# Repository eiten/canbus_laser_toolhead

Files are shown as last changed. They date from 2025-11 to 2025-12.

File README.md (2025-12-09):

# 🔥 Laser CANbus Toolhead PCB

> 🌍 **Languages:** [English](README.md) | [Deutsch](README.de.md)

A compact, robust toolhead board for Klipper-based laser engravers and cutters (CoreXY). This board integrates power supply, laser driver logic, CAN-Bus communication, and input shaping (ICM-20602) in the smallest possible space.

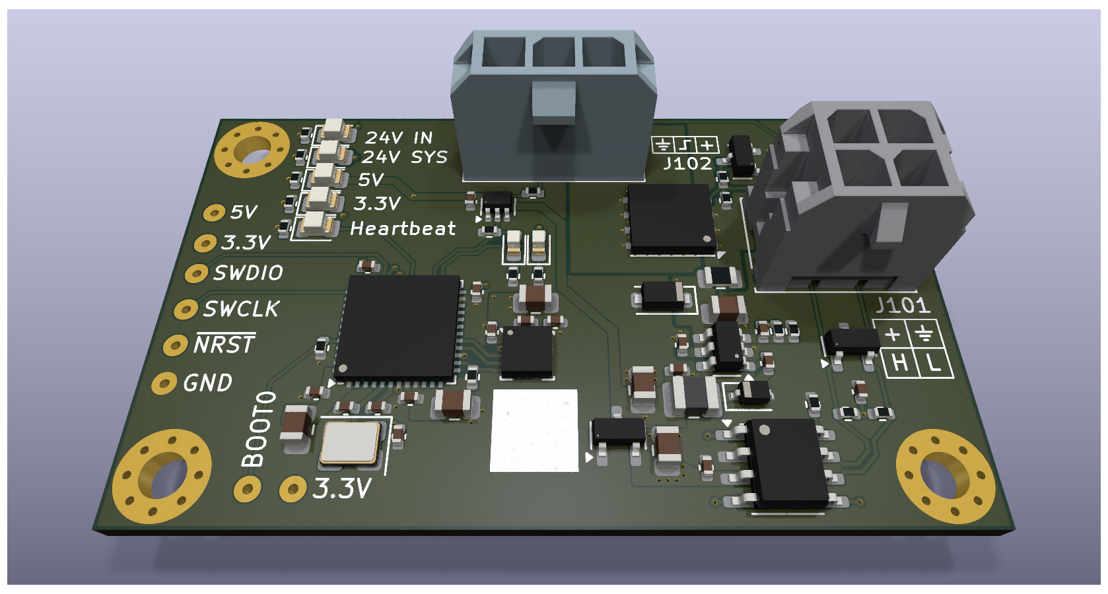
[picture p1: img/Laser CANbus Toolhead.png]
Laser CANbus Toolhead PCB


## 📚 Contents

<!-- @import "[TOC]" {cmd="toc" depthFrom=1 depthTo=6 orderedList=false} -->

<!-- code_chunk_output -->

- [🔥 Laser CANbus Toolhead PCB](#-laser-canbus-toolhead-pcb)
  - [📚 Contents](#-contents)
  - [✨ Features](#-features)
    - [🧠 Microcontroller](#-microcontroller)
    - [🔗 CAN-Bus Communication](#-can-bus-communication)
    - [📊 Input Shaping](#-input-shaping)
    - [⚡ Laser Power Control](#-laser-power-control)
    - [🎛️ Laser Signal Control](#️-laser-signal-control)
    - [🔌 Power Supply](#-power-supply)
    - [🚨 Diagnostics & Monitoring](#-diagnostics--monitoring)
  - [📋 Klipper Configuration](#-klipper-configuration)
    - [Basic MCU Setup](#basic-mcu-setup)
    - [Input Shaping (ICM-20602)](#input-shaping-icm-20602)
    - [Laser Control](#laser-control)
  - [🔌 Pinout & Connector Assignment](#-pinout--connector-assignment)
    - [J101 - Power & CAN Input (Micro-Fit 3.0, 2x2, THT)](#j101---power--can-input-micro-fit-30-2x2-tht)
    - [J102 - Laser Output (Micro-Fit 3.0, 1x3, THT)](#j102---laser-output-micro-fit-30-1x3-tht)
    - [Debug/Programming Header (Back Side)](#debugprogramming-header-back-side)
  - [🔧 Installation & Setup](#-installation--setup)
    - [1. CAN-Bus Configuration](#1-can-bus-configuration)
    - [2. Firmware Flash](#2-firmware-flash)
    - [3. Find UUID](#3-find-uuid)
  - [⚠️ Safety Notes](#️-safety-notes)
  - [🛠️ BOM (Bill of Materials) - Highlights](#️-bom-bill-of-materials---highlights)
  - [🛠️ Technical Specifications](#️-technical-specifications)
  - [📝 Changelog](#-changelog)
    - [Rev. 1](#rev-1)
    - [Rev. 0 (Initial Release)](#rev-0-initial-release)
  - [📚 Additional Resources](#-additional-resources)
  - [License](#license)

<!-- /code_chunk_output -->

## ✨ Features

### 🧠 Microcontroller
- **MCU:** STM32F072CBU6 (Cortex-M0, 48MHz, CAN-capable)
- **Stability:** 12MHz crystal for maximum CAN-Bus stability
- **Firmware:** Klipper-compatible

### 🔗 CAN-Bus Communication
- **Transceiver:** SN65HVD230 with ESD protection
- **Termination:** Split termination via solder jumper
- **Slope Control:** Switchable for EMI optimization

### 📊 Input Shaping
- **Sensor:** On-board ICM-20602 accelerometer/gyroscope (SPI)
- **Purpose:** Klipper resonance measurement for perfect print quality
- **Advantage:** Better availability and modern sensor technology

### ⚡ Laser Power Control
- **Circuit:** 24V / 6A High-Side Switch (CJAC70P06 P-MOSFET, 60V rated)
- **Peak Current:** 8A capability
- **Soft-Start:** Limits inrush current (Rise-time ~1.2ms)
- **Safety:** Hardware pull-down prevents unwanted activation
- **Limitation:** Max 6A limited by Micro Fit 3.0 connector with 0.75mm² wire

### 🎛️ Laser Signal Control
- **PWM:** 5V Level-shifted via 74AHCT1G125 buffer
- **Quality:** Clean edges, true hardware PWM via STM32 timer
- **Compatibility:** Common diode lasers

### 🔌 Power Supply
- **Input:** 24V with 250mA PTC fuse and SMF24A TVS diode
- **5V Rail:** MP2459 Buck converter (up to 60V input tolerant)
- **3.3V Rail:** XC6206 LDO for MCU and peripherals

### 🚨 Diagnostics & Monitoring
- **Power LEDs:** 24V In, 24V Sys, 5V, 3.3V
- **Status LEDs:** Laser Enable, Laser PWM, Heartbeat

## 📋 Klipper Configuration

### Basic MCU Setup
```ini
[mcu toolhead]
canbus_uuid: <your-uuid>  # Find with "ls /dev/serial/by-id/*" or "~/klippy-env/bin/python ~/klipper/scripts/canbus_query.py can0"

[temperature_sensor toolhead_mcu]
sensor_type: temperature_mcu
sensor_mcu: toolhead
```

### Input Shaping (ICM-20602)
```ini
[mpu9250]
cs_pin: toolhead:PA4
spi_bus: spi1
#axes_map: x,y,z  # Configure according to your printer orientation

[resonance_tester]
accel_chip: mpu9250
probe_points:
    150, 150, 20  # Adjust to your bed size
```

### Laser Control
```ini
# Laser PWM Signal
[output_pin laser_pwm]
pin: toolhead:PB14
pwm: True
cycle_time: 0.001          # 1kHz PWM frequency
shutdown_value: 0          # Safety: laser off during emergency

# Laser Enable (optional)
[output_pin laser_enable]
pin: toolhead:PB15
value: 0
shutdown_value: 0

# Heartbeat LED (optional)
[output_pin heartbeat]
pin: toolhead:PA9
pwm: True
cycle_time: 1.0
```

## 🔌 Pinout & Connector Assignment

### J101 - Power & CAN Input (Micro-Fit 3.0, 2x2, THT)
| Pin | Signal | Description |
|-----|---|---|
| 1 | **+24V** | Main power input (High Current) |
| 2 | **GND** | Ground |
| 3 | **CAN_H** | CAN-Bus High Signal |
| 4 | **CAN_L** | CAN-Bus Low Signal |

### J102 - Laser Output (Micro-Fit 3.0, 1x3, THT)
| Pin | Signal | Description |
|-----|---|---|
| 1 | **GND** | Laser Ground |
| 2 | **PWM** | 5V PWM Signal (Level-Shifted) |
| 3 | **+24V** | Switched Laser Power (Soft-Start) |

### Debug/Programming Header (Back Side)
| Pad | Pin | Signal | Function |
|-----|-----|---|---|
| 1 | - | **5V** | 5V Supply (from Programmer) |
| 2 | - | **3.3V** | VTref (Reference Voltage) |
| 3 | PA13 | **SWDIO** | Serial Wire Debug I/O |
| 4 | PA14 | **SWCLK** | Serial Wire Debug Clock |
| 5 | - | **NRST** | Reset Signal |
| 6 | - | **GND** | Ground |

> **💡 Bootloader Mode:** To force the STM32 into DFU/Bootloader mode (e.g., for initial flash with Katapult), bridge the **BOOT0** pad with **3.3V** during power-on.

## 🔧 Installation & Setup

### 1. CAN-Bus Configuration
- Set CAN-Bus termination according to position in network
- Baud rate: 1 Mbit/s (Klipper standard)

### 2. Firmware Flash
1. Put board into DFU mode (bridge BOOT0)
2. Compile Klipper for STM32F072 with CAN support
3. Flash firmware: `make flash FLASH_DEVICE=<dfu-device>`

### 3. Find UUID
```bash
~/klippy-env/bin/python ~/klipper/scripts/canbus_query.py can0
```

## ⚠️ Safety Notes

- **Laser Safety:** Always wear protective eyewear
- **Power Supply:** Only operate with 24V DC
- **Initial Setup:** Slowly ramp up laser power
- **Emergency:** Hardware pull-down ensures safe state

## 🛠️ BOM (Bill of Materials) - Highlights

| Component | Value/Type | Function | Package | Order Code |
|---|---|---|---|---|
| **U101** | STM32F072CBU6 | Main Microcontroller | UFQFPN-48 | STM32F072CBU6 |
| **U102** | MP2459GJ-Z | Buck Converter 24V→5V | TSOT-23-8 | MP2459GJ-Z |
| **U105** | SN65HVD230DR | CAN-Bus Transceiver | SOIC-8 | SN65HVD230DR |
| **U106** | ICM-20602 | 6-Axis IMU (Accelerometer/Gyroscope) | LGA-16 | ICM-20602 |
| **Q101** | CJAC70P06 | P-MOSFET (Laser Switch, 60V) | SOIC-8 | CJAC70P06 |
| **D101** | SMF24A | TVS Diode (Overvoltage Protection) | DO-214AC | SMF24A |
| **F101** | 1812L025 | PTC Fuse 250mA | 1812 | 1812L025 |
| **Y101** | 12MHz | Crystal for CAN Stability | HC-49/S | 12MHz Crystal |
| **J101/J102** | Micro-Fit 3.0 | THT Connectors | THT | Micro-Fit 3.0 THT |

## 🛠️ Technical Specifications

| Parameter | Value | Unit |
|---|---|---|
| **Input Voltage** | 24 ± 2 | V |
| **Laser Current (max)** | 4 | A |
| **CAN Baud Rate** | 1 | Mbit/s |
| **PWM Frequency** | 1 | kHz |
| **Soft-Start Time** | ~1.2 | ms |
| **Operating Temperature** | -10 to +70 | °C |
| **Dimensions** | TBD | mm |

## 📝 Changelog

### Rev. 0.1
- **Transistor Upgrade:** Replaced MOSFET with CJAC70P06 (60V voltage rating)
- **Sensor Upgrade:** Changed from ADXL345 to ICM-20602 (better availability, modern 6-axis IMU)
- **Connector Change:** Micro Fit 3.0 connectors changed from SMD to THT mounting
- **Silkscreen Enhancement:** Added connector pin assignments to silkscreen for easier assembly
- **Layout Improvements:** Cleaned up component placement and optimized routing
- **Documentation:** Updated overview image to reflect current design
- **BOM Update:** Added component order numbers and updated production data
- **Production Files:** Updated assembly and production files with current components

### Rev. 0.0 (Initial Release)
- Initial PCB design with STM32F072CBU6 microcontroller
- CAN-Bus communication with SN65HVD230 transceiver
- 24V/4A laser power control with AO4407A MOSFET
- ADXL345 accelerometer for input shaping
- MP2459 buck converter for power supply

## 📚 Additional Resources

- [Klipper Documentation](https://www.klipper3d.org/Config_Reference.html)
- [CAN-Bus Setup Guide](https://www.klipper3d.org/CANBUS.html)
- [Input Shaping](https://www.klipper3d.org/Resonance_Compensation.html)
- [Katapult Firmware Flasher](https://github.com/Arksine/katapult)

## License

This project is licensed under the **Creative Commons Attribution-NonCommercial-ShareAlike 4.0 International License** (CC BY-NC-SA 4.0).



This means you are free to:
- **Share** — copy and redistribute the material in any medium or format
- **Adapt** — remix, transform, and build upon the material

Under the following terms:
- **Attribution** — You must give appropriate credit, provide a link to the license, and indicate if changes were made
- **NonCommercial** — You may not use the material for commercial purposes
- **ShareAlike** — If you remix, transform, or build upon the material, you must distribute your contributions under the same license

For the full license text, visit: https://creativecommons.org/licenses/by-nc-sa/4.0/

---

> **Note:** The original documentation is in German ([README.de.md](README.de.md)). This English version is a translation for international users.

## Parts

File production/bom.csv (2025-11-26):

Designator | Footprint | Quantity | Value | LCSC Part #
C101, C102, C115 | 0402 | 3 | 33p | C1562
C103, C110, C116, C121, C124 | 0805 | 5 | 10u | C440198
C104, C105, C106, C107, C108, C109, C111, C113, C114, C117, C118, C120, C122, C123 | 0402 | 14 | 100n | C307331
C112 | 0805 | 1 | 22u | C45783
C119 | 0402 | 1 | 4n7 | C1538
D101 | D_SOD-123F | 1 | SMF24A | C19077514
D102 | D_SOD-323 | 1 | 1N5819WS | C191023
D103 | SOT-23 | 1 | PESD1CAN | C343993
D104, D105, D106, D107 | 0805 | 4 | green | C2297
D108 | 0805 | 1 | yellow | C2296
D109, D110 | 0603 | 2 | red | C2286
F101 | 0805 | 1 | 250mA | C20608679
J101 | Molex_Micro-Fit_3.0_43045-0412_2x02_P3.00mm_Vertical | 1 | In | C492540
J102 | Molex_Micro-Fit_3.0_43650-0315_1x03_P3.00mm_Vertical | 1 | Laser | C705183
L101 | 1008 | 1 | L | C5832376
Q102 | SOT-23 | 1 | 2N7002 | C8545
Q103 | AO_DFN-8-1EP_5.55x5.2mm_P1.27mm_EP4.12x4.6mm | 1 | CJAC70P06 | C2898279
R101, R103, R107, R108, R112, R113 | 0402 | 6 | 10k | C25744
R102 | 0402 | 1 | 51k | C25794
R104, R105, R106 | 0402 | 3 | 100k | C25741
R109, R118 | 0402 | 2 | 1k | C11702
R110, R111 | 0402 | 2 | 60R4 | C60310
R114, R115 | 0402 | 2 | 33k | C25779
R116 | 0402 | 1 | 3.3k | C25890
R117 | 0402 | 1 | 220R | C25091
R119, R120 | 0402 | 2 | 470R | C25117
U101 | QFN-48-1EP_7x7mm_P0.5mm_EP5.6x5.6mm | 1 | STM32F072CBUx | C92504
U102 | SOT-23-6 | 1 | MP2459 | C39578
U103 | SOT-23-3 | 1 | XC6206P332MR-G | C5446
U104 | SOT-353_SC-70-5 | 1 | 74AHCT1G125 | C7484
U105 | SOIC-8_3.9x4.9mm_P1.27mm | 1 | SN65HVD230 | C12084
U107 | LGA-16_3x3mm_P0.5mm_LayoutBorder3x5y | 1 | ICM-20602
Y101 | Crystal_SMD_3225-4Pin_3.2x2.5mm | 1 | 12 MHz | C9002

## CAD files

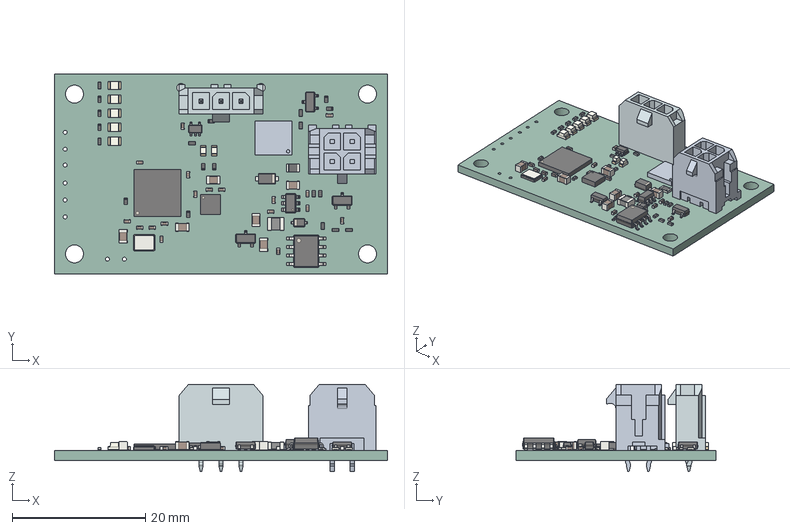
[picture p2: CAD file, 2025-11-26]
Laser CANbus Toolhead.step
50.0 x 30.0 x 13.1 mm
R_0402_1005Metric x 20
LED_0805_2012Metric x 5
C_0402_1005Metric x 18
SOT-23 x 2
Laser CANbus Toolhead 1.9.1
SOIC-8_3.9x4.9mm_P1.27mm
Crystal_SMD_3225-4Pin_3.2x2.5mm
SOT-23-6
D_SOD-323
C_0805_2012Metric x 6
LGA-16_3x3mm_P0.5mm_LayoutBorder3x5y
Nordic_AQFN-73-1EP_7x7mm_P0.5mm
Fuse_0805_2012Metric
LED_0603_1608Metric x 2
SOT-353_SC-70-5
SOT-23-3
L_1008_2520Metric
D_SOD-123F
Laser CANbus Toolhead_PCB

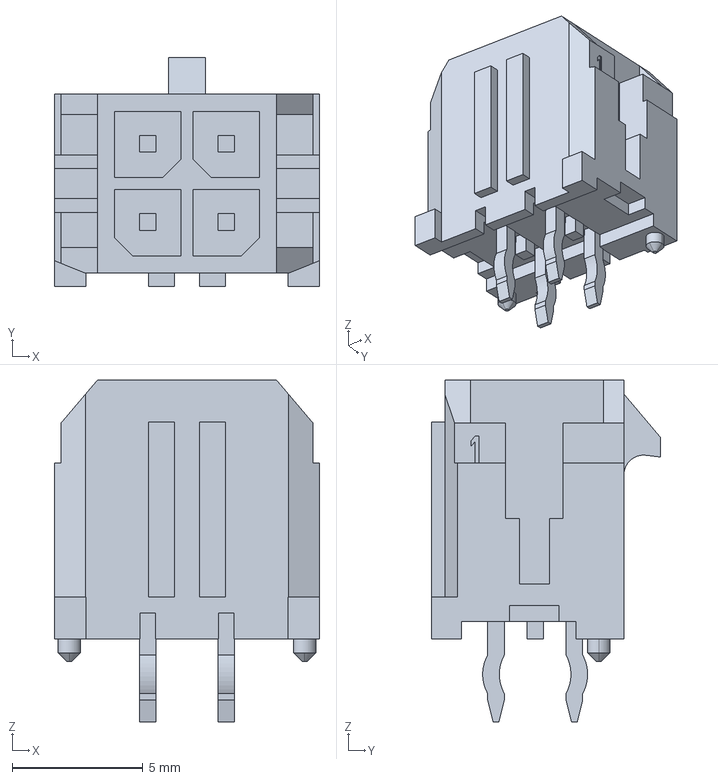
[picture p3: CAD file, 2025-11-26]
3D/0430450412.stp
10.2 x 8.77 x 13.1 mm

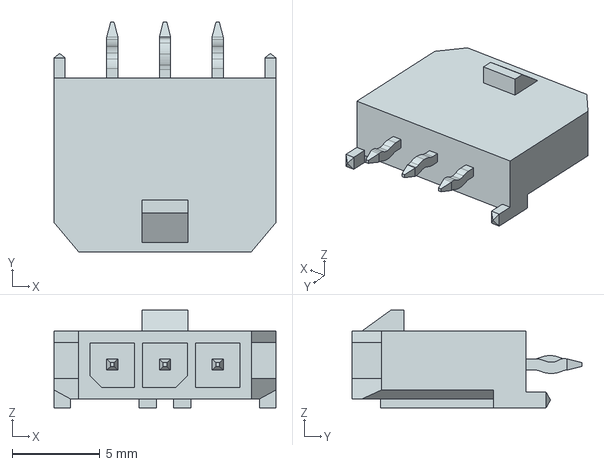
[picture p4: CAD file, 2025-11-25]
3D/0436500315.stp
12.7 x 13.1 x 5.57 mm

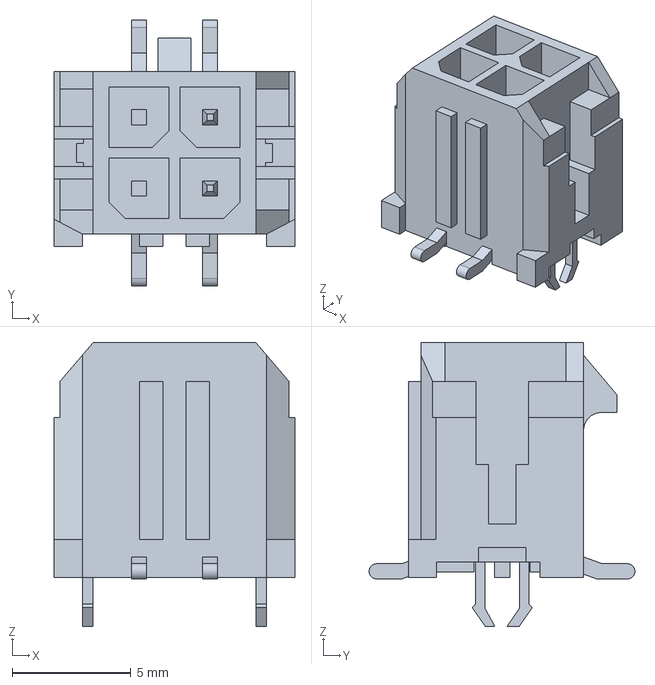
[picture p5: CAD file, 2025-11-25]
3D/0430450415.stp
10.2 x 11.2 x 12.0 mm

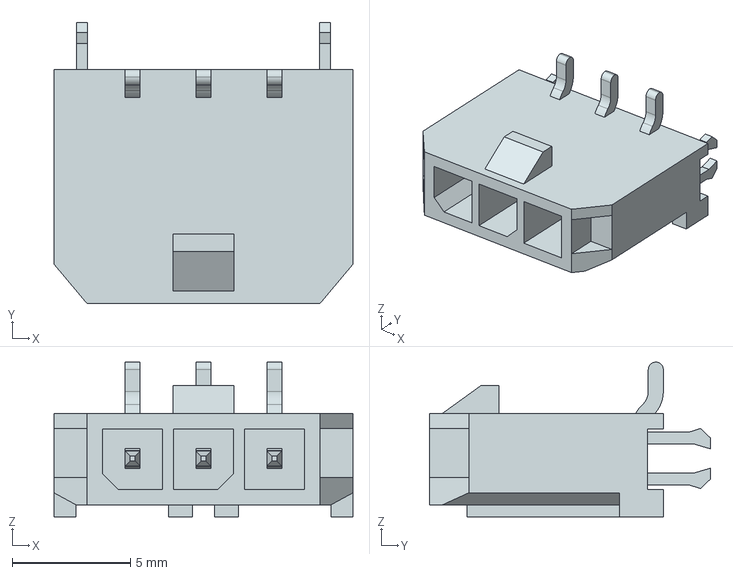
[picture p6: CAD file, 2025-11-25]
3D/0436500321.stp
12.7 x 11.9 x 6.55 mm

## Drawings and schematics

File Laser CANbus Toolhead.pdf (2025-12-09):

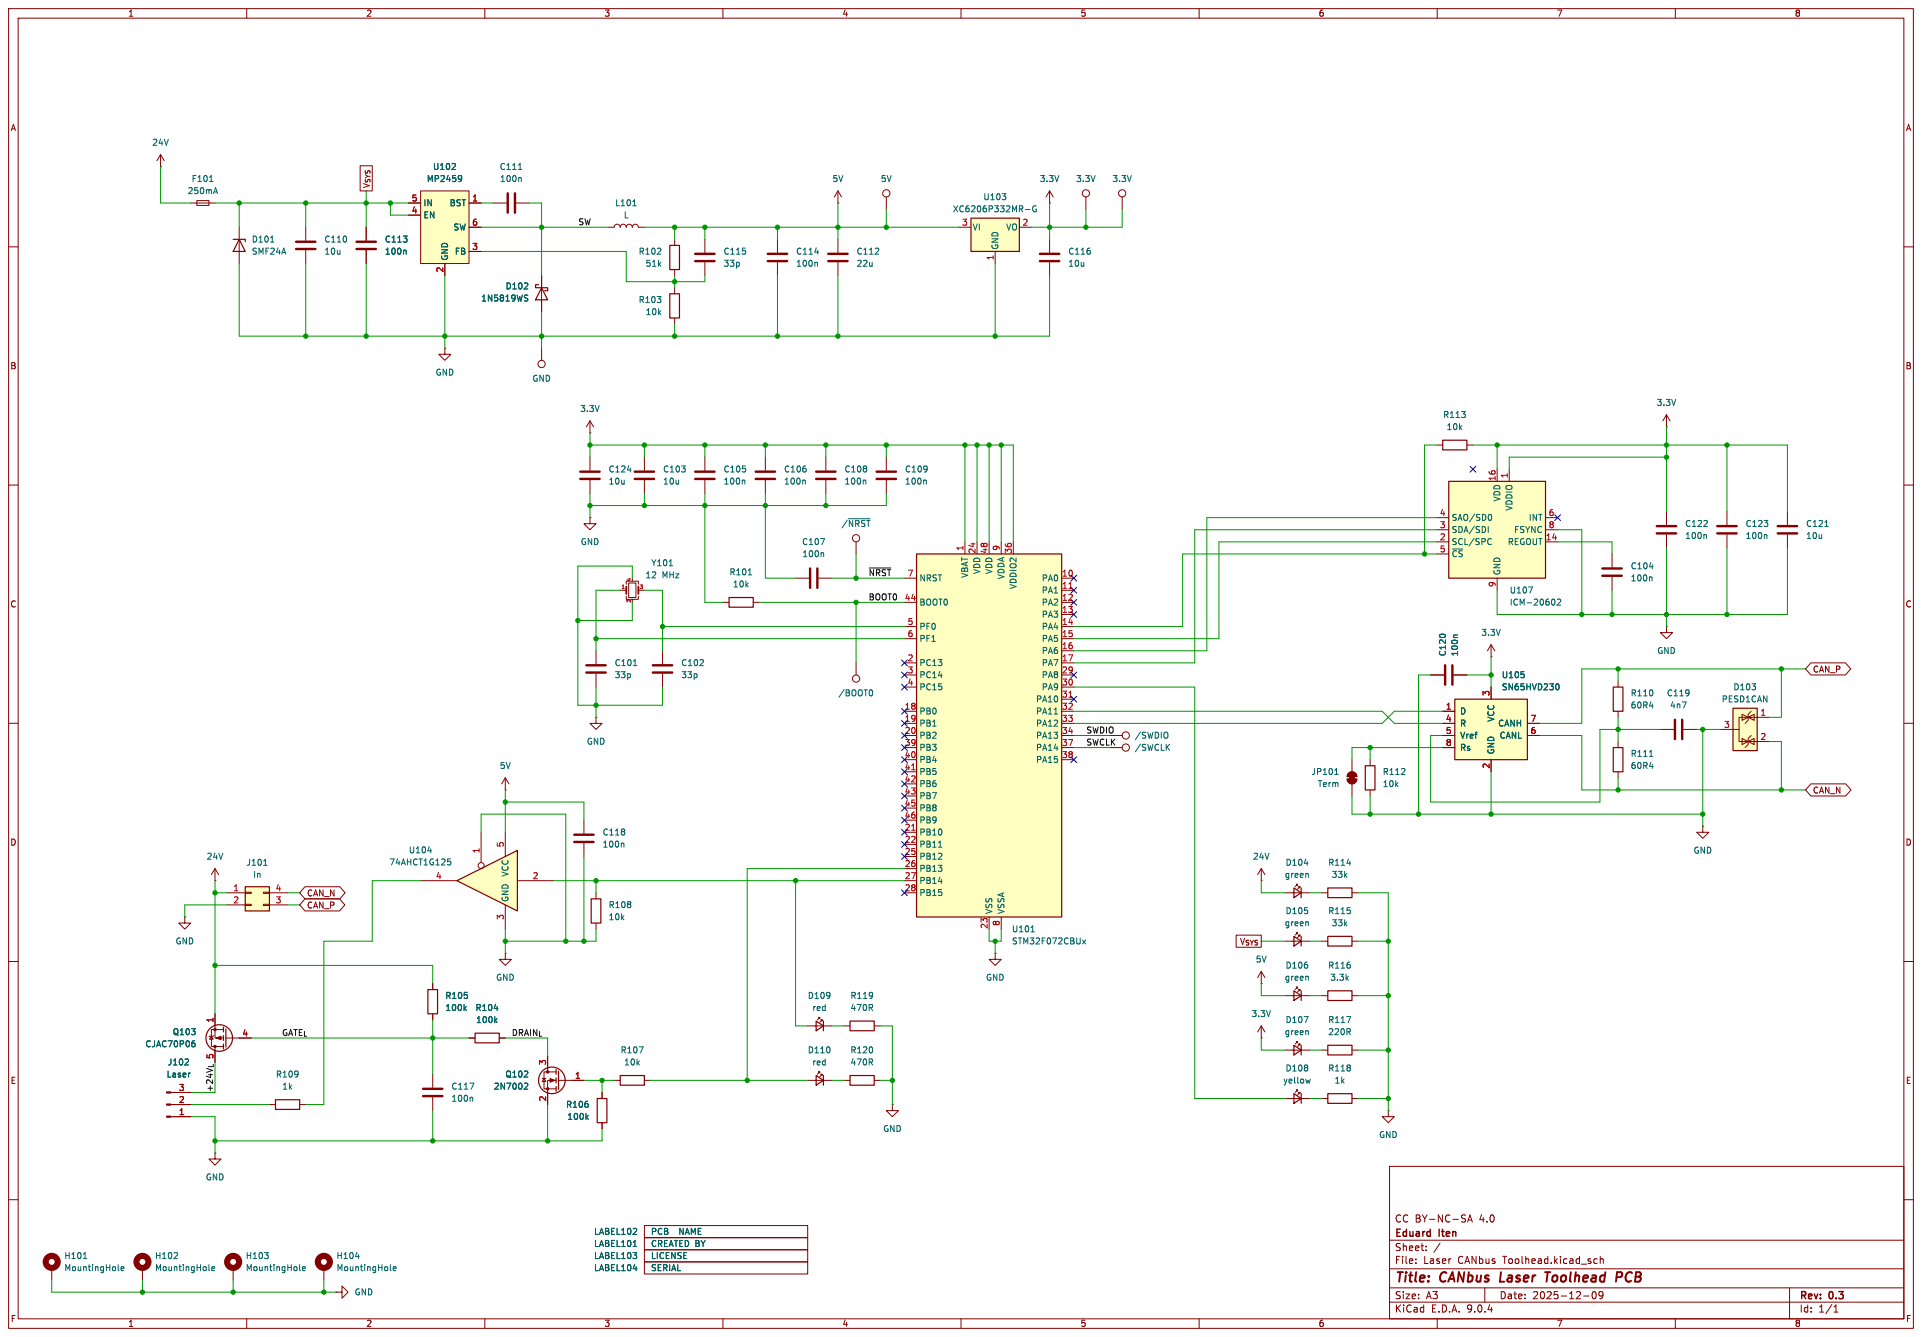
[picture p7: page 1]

1 VDD 24 VDD 48 VSS 23 VDDA

Id: 1/1 Title: CANbus Laser Toolhead PCB

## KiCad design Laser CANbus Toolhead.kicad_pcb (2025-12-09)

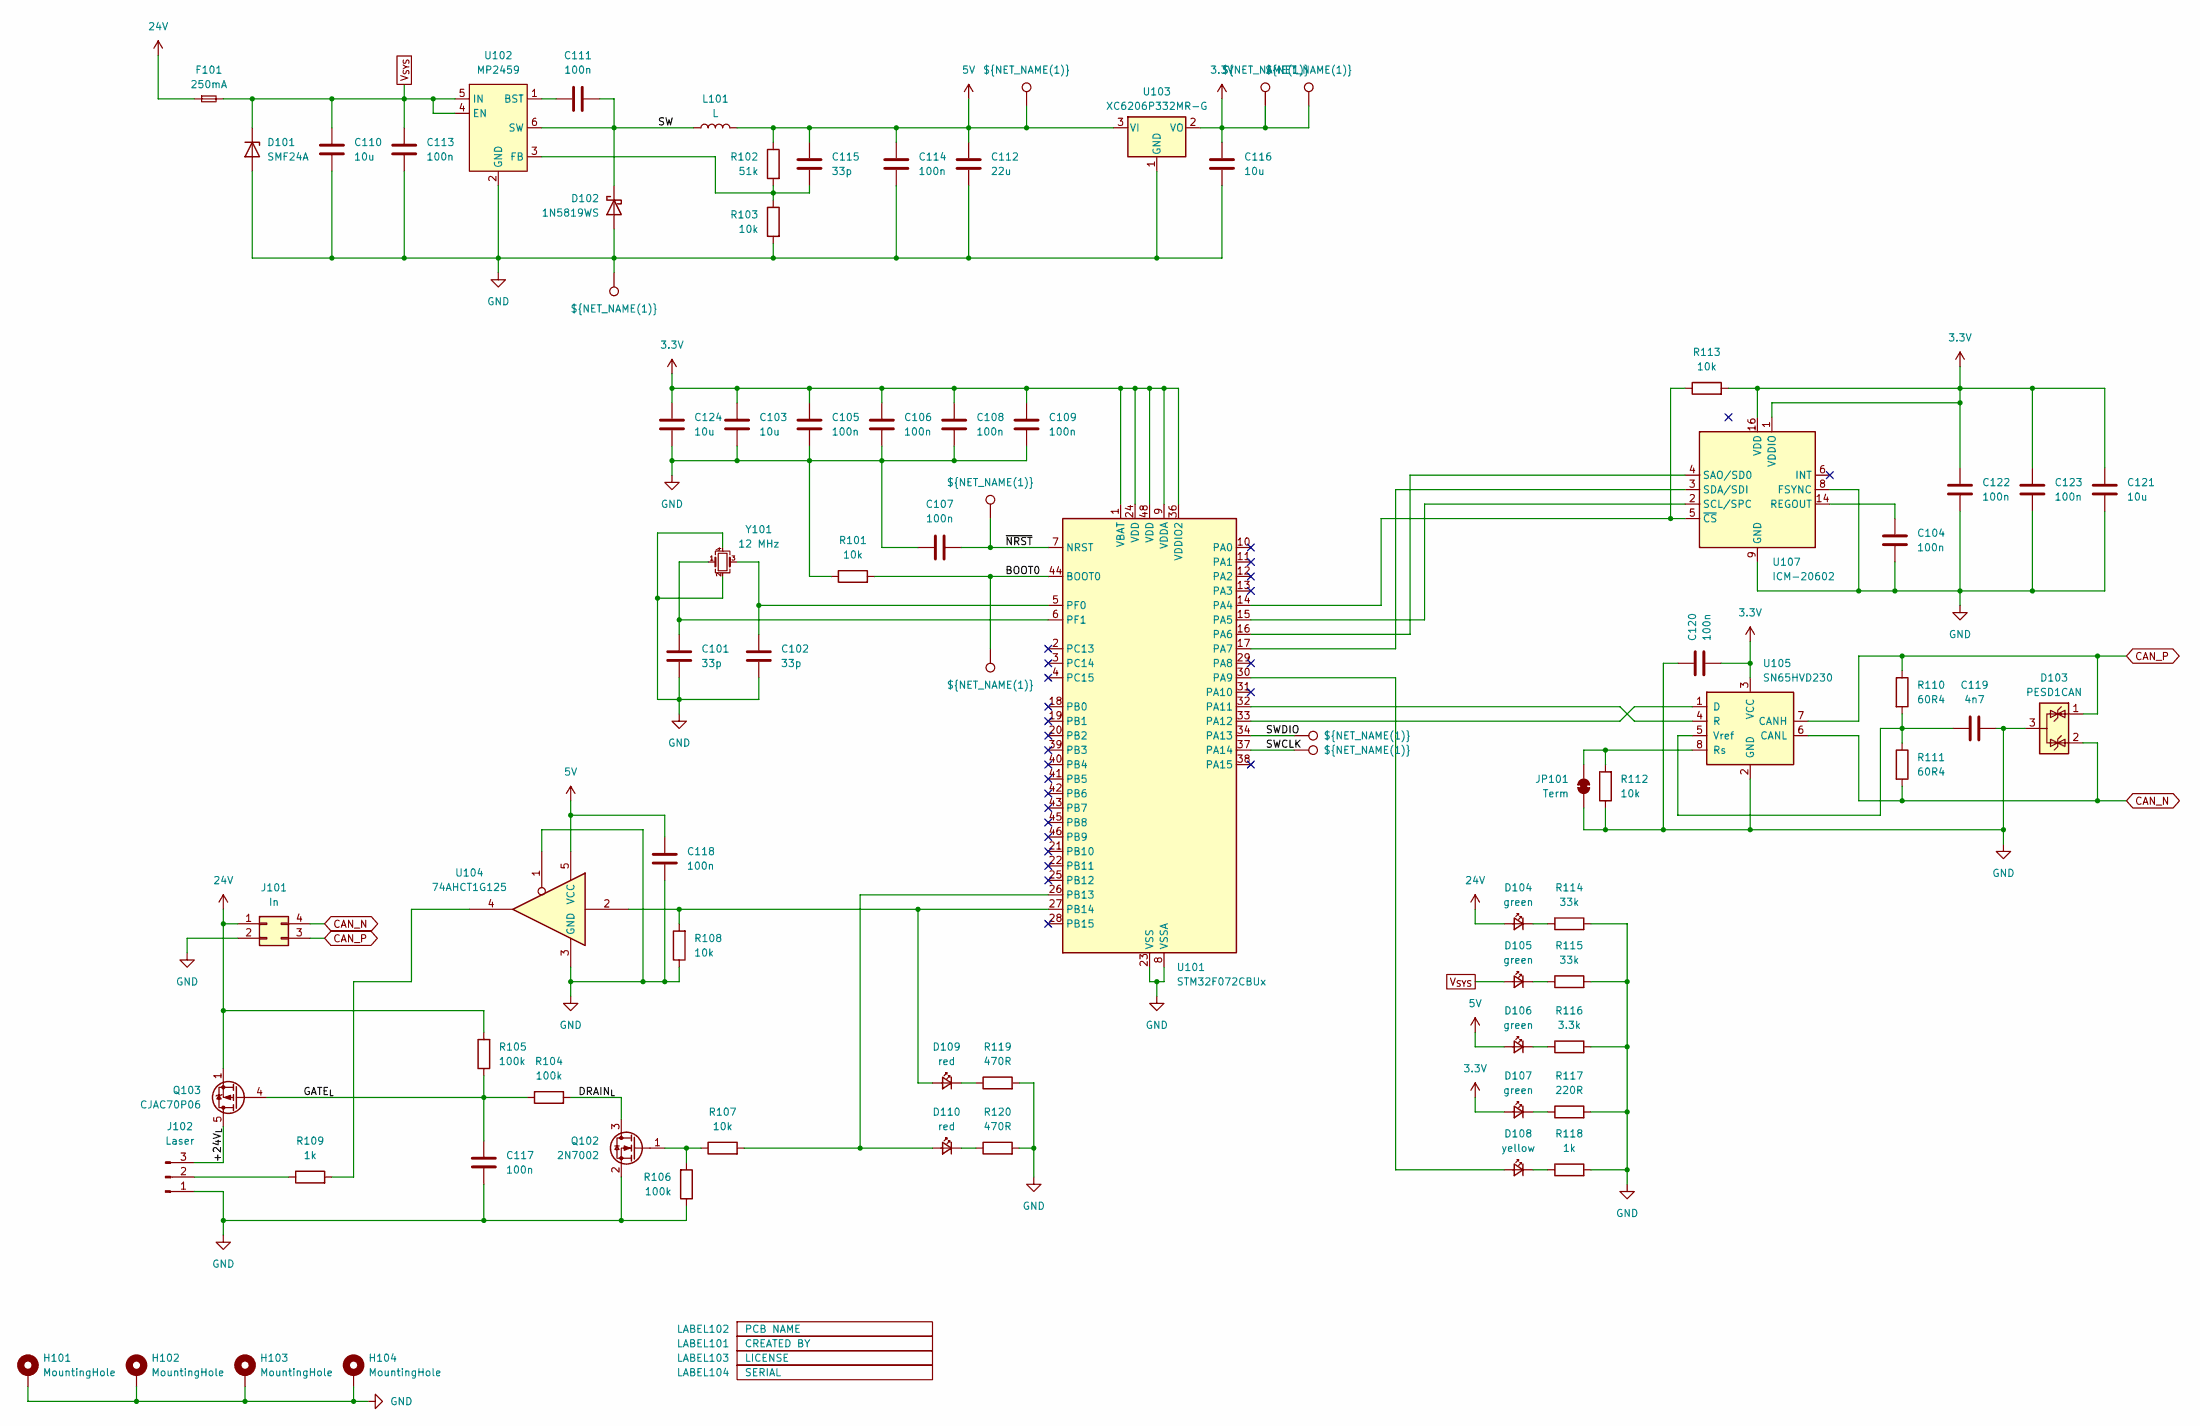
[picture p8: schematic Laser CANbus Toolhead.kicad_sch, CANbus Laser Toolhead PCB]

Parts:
C101, C102, C115: 33p; C_0402_1005Metric; Manufacturer Part # 0402CG330J500NT; LCSC Part # C1562
C103, C110, C116, C121, C124: 10u; C_0805_2012Metric; Manufacturer Part # GRM21BR61H106KE43L; LCSC Part # C440198
C104, C105, C106, C107, C108, C109, C111, C113, C114, C117, C118, C120, C122, C123: 100n; C_0402_1005Metric; Manufacturer Part # CL05B104KB54PNC; LCSC Part # C307331
C112: 22u; C_0805_2012Metric; Manufacturer Part # CL21A226MAQNNNE; LCSC Part # C45783
C119: 4n7; C_0402_1005Metric; Manufacturer Part # 0402B472K500NT; LCSC Part # C1538
D101: SMF24A; D_SOD-123F; Manufacturer Part # SMF24A; LCSC Part # C19077514
D102: 1N5819WS; D_SOD-323; Manufacturer Part # 1N5819WS; LCSC Part # C191023
D103: PESD1CAN; SOT-23; Manufacturer Part # PESD1CAN; LCSC Part # C343993
D104, D105, D106, D107: green; LED_0805_2012Metric; Manufacturer Part # KT-0805G; LCSC Part # C2297
D108: yellow; LED_0805_2012Metric; Manufacturer Part # KT-0805Y; LCSC Part # C2296
D109, D110: red; LED_0603_1608Metric; Manufacturer Part # KT-0603R; LCSC Part # C2286
F101: 250mA; Fuse_0805_2012Metric; Manufacturer Part # LUTE 0805L025/36XR; LCSC Part # C20608679
H101, H102, H103, H104: MountingHole; MountingHole_2.7mm_Pad_Via
J101: In; Molex_Micro-Fit_3.0_43045-0412_2x02_P3.00mm_Vertical; Manufacturer Part # M3025V-2x2P; LCSC Part # C492540
J102: Laser; Molex_Micro-Fit_3.0_43650-0315_1x03_P3.00mm_Vertical; Manufacturer Part # M3025V-1x3P; LCSC Part # C705183
JP101: Term; SolderJumper-2_P1.3mm_Bridged_RoundedPad1.0x1.5mm
L101: L; L_1008_2520Metric; Manufacturer Part # FTC252012S100MBCA; LCSC Part # C5832376
LABEL101: CREATED BY; EduardIten
LABEL102: PCB NAME; CLT Rev. xxx
LABEL103: LICENSE; CC_BY_NC_SA 4
LABEL104: SERIAL; SERIAL_No
Q102: 2N7002; SOT-23; Manufacturer Part # 2N7002; LCSC Part # C8545
Q103: CJAC70P06; AO_DFN-8-1EP_5.55x5.2mm_P1.27mm_EP4.12x4.6mm; Manufacturer Part # CJAC70P06; LCSC Part # C2898279
R101, R103, R107, R108, R112, R113: 10k; R_0402_1005Metric; Manufacturer Part # 0402WGF1002TCE; LCSC Part # C25744
R102: 51k; R_0402_1005Metric; Manufacturer Part # 0402WGF5102TCE; LCSC Part # C25794
R104, R105, R106: 100k; R_0402_1005Metric; Manufacturer Part # 0402WGF1003TCE; LCSC Part # C25741
R109, R118: 1k; R_0402_1005Metric; Manufacturer Part # 0402WGF1001TCE; LCSC Part # C11702
R110, R111: 60R4; R_0402_1005Metric; Manufacturer Part # 0402WGF604JTCE; LCSC Part # C60310
R114, R115: 33k; R_0402_1005Metric; Manufacturer Part # 0402WGF3302TCE; LCSC Part # C25779
R116: 3.3k; R_0402_1005Metric; Manufacturer Part # 0402WGF3301TCE; LCSC Part # C25890
R117: 220R; R_0402_1005Metric; Manufacturer Part # 0402WGF2200TCE; LCSC Part # C25091
R119, R120: 470R; R_0402_1005Metric; Manufacturer Part # 0402WGF4700TCE; LCSC Part # C25117
TP101, TP102, TP103, TP104, TP105, TP106, TP107, TP108: ${NET_NAME(1)}; NAMED_TEST_POINT
U101: STM32F072CBUx; QFN-48-1EP_7x7mm_P0.5mm_EP5.6x5.6mm; Manufacturer Part # STM32F072CBU6; LCSC Part # C92504
U102: MP2459; SOT-23-6; Manufacturer Part # MP2459GJ-Z; LCSC Part # C39578
U103: XC6206P332MR-G; SOT-23-3; Manufacturer Part # XC6206P332MR-G; LCSC Part # C5446
U104: 74AHCT1G125; SOT-353_SC-70-5; Manufacturer Part # SN74AHCT1G125DBVR; LCSC Part # C7484
U105: SN65HVD230; SOIC-8_3.9x4.9mm_P1.27mm; Manufacturer Part # SN65HVD230DR; LCSC Part # C12084
U107: ICM-20602; LGA-16_3x3mm_P0.5mm_LayoutBorder3x5y
Y101: 12 MHz; Crystal_SMD_3225-4Pin_3.2x2.5mm; Manufacturer Part # X322512MSB4SI; LCSC Part # C9002

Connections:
3.3V: C103.1, C105.1, C106.1, C108.1, C109.1, C116.1, C120.2, C121.1, C122.1, C123.1, C124.1, D107.2 (A), R113.2, TP102.1, TP108.1, U101.1 (VBAT), U101.9 (VDDA), U101.24 (VDD), U101.36 (VDDIO2), U101.48 (VDD), U103.2 (VO), U105.3 (VCC), U107.1 (VDDIO), U107.16 (VDD)
5V: C112.1, C114.1, C115.1, C118.1, D106.2 (A), L101.2, R102.1, TP101.1, U103.3 (VI), U104.5 (VCC)
24V: D104.2 (A), F101.1, J101.1, Q103.1 (S), Q103.2 (S), Q103.3 (S), R105.2
/+24V_{L}: J102.3, Q103.5 (D)
/BOOT0: R101.2, TP107.1, U101.44 (BOOT0)
/DRAIN_{L}: Q102.3 (D), R104.2
/GATE_{L}: C117.1, Q103.4 (G), R104.1, R105.1
/SW: C111.2, D102.1 (K), L101.1, U102.6 (SW)
/SWCLK: TP106.1, U101.37 (PA14)
/SWDIO: TP105.1, U101.34 (PA13)
/~NRST: C107.2, TP104.1, U101.7 (NRST)
CAN_N: D103.2 (K), J101.4, R111.2, U105.6 (CANL)
CAN_P: D103.1 (K), J101.3, R110.1, U105.7 (CANH)
GND: C101.2, C102.2, C103.2, C104.2, C105.2, C106.2, C107.1, C108.2, C109.2, C110.2, C112.2, C113.2, C114.2, C116.2, C117.2, C118.2, C119.2, C120.1, C121.2, C122.2, C123.2, C124.2, D101.2 (A), D102.2 (A), D103.3 (A), H101.1, H102.1, H103.1, H104.1, J101.2, J102.1, JP101.2 (B), Q102.2 (S), R101.1, R103.2, R106.1, R108.1, R112.1, R114.2, R115.2, R116.2, R117.2, R118.2, R119.2, R120.2, TP103.1, U101.8 (VSSA), U101.23 (VSS), U101.35 (VSS), U101.47 (VSS), U101.49 (VSS), U102.2 (GND), U103.1 (GND), U104.1, U104.3 (GND), U105.2 (GND), U107.8 (FSYNC), U107.9 (GND), U107.10 (GND), U107.11 (GND), U107.12 (GND), U107.13 (GND), U107.15 (GND), Y101.2, Y101.4
unnamed: D104.1 (K), R114.1
unnamed: D105.1 (K), R115.1
unnamed: D106.1 (K), R116.1
unnamed: D107.1 (K), R117.1
unnamed: D108.2 (A), U101.30 (PA9)
unnamed: D108.1 (K), R118.1
unnamed: D109.2 (A), R108.2, U101.27 (PB14), U104.2
unnamed: D109.1 (K), R119.1
unnamed: D110.2 (A), R107.2, U101.26 (PB13)
unnamed: D110.1 (K), R120.1
unnamed: J102.2, R109.1
unnamed: JP101.1 (A), R112.2, U105.8 (Rs)
unnamed: Q102.1 (G), R106.2, R107.1
unnamed: R109.2, U104.4
unnamed: R113.1, U101.14 (PA4), U107.5 (~CS)
unnamed: U101.15 (PA5), U107.2 (SCL/SPC)
unnamed: U101.16 (PA6), U107.4 (SAO/SD0)
unnamed: U101.17 (PA7), U107.3 (SDA/SDI)
unnamed: U101.32 (PA11), U105.4 (R)
unnamed: U101.33 (PA12), U105.1 (D)
unnamed: C102.1, U101.5 (PF0), Y101.3
unnamed: C101.1, U101.6 (PF1), Y101.1
unnamed: C111.1, U102.1 (BST)
unnamed: C115.2, R102.2, R103.1, U102.3 (FB)
unnamed: C119.1, R110.2, R111.1, U105.5 (Vref)
unnamed: C104.1, U107.14 (REGOUT)
V_{SYS}: C110.1, C113.1, D101.1 (K), D105.2 (A), F101.2, U102.4 (EN), U102.5 (IN)

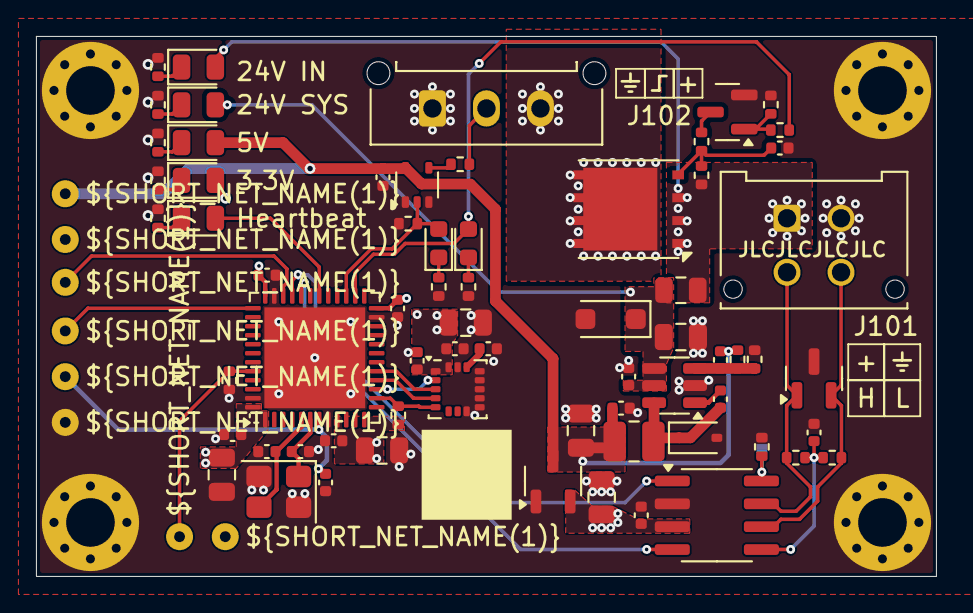
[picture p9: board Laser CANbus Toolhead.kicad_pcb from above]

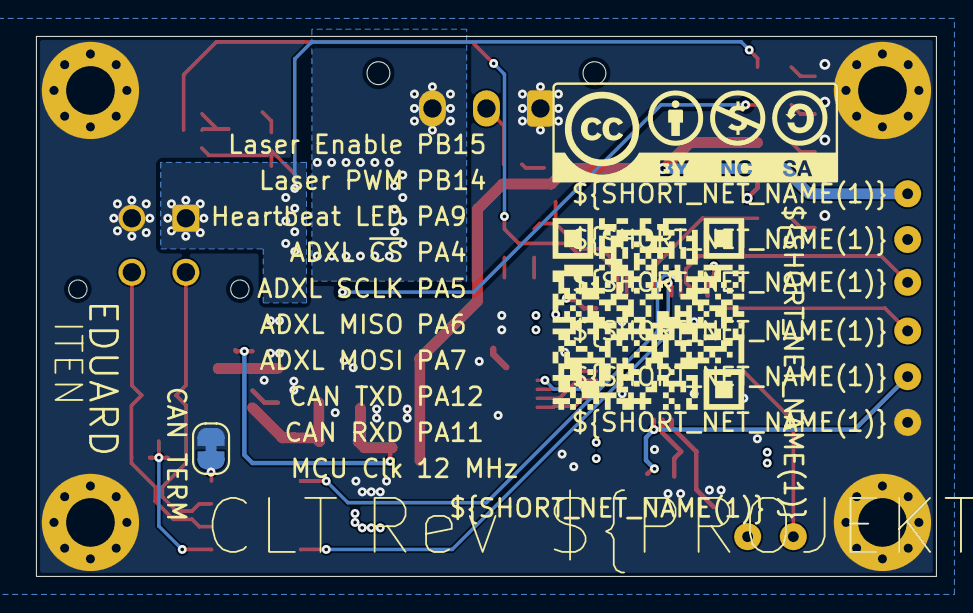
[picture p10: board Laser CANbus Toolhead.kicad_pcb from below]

Board: 4 copper layers, 50.0 x 30.0 mm, 84 parts (4 on the bottom side), 41 nets.

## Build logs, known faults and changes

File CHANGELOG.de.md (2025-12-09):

# 📝 Changelog

*🇬🇧 English version: [CHANGELOG.md](CHANGELOG.md)*

Alle wichtigen Änderungen am Laser CANbus Toolhead PCB Projekt werden in dieser Datei dokumentiert.

Das Format basiert auf [Keep a Changelog](https://keepachangelog.com/en/1.0.0/),
und dieses Projekt folgt [Semantic Versioning](https://semver.org/spec/v2.0.0.html) für Hardware-Revisionen.

## [Unveröffentlicht]

## [Rev. 0.1] - 2025-11-26

### 🔧 Hardware-Änderungen
- **Transistor Upgrade:** MOSFET durch CJAC70P06 ersetzt (60V Spannungsfestigkeit, verbesserte Sicherheitsmarge)
- **Sensor Upgrade:** Wechsel von ADXL345 zu ICM-20602 (bessere Verfügbarkeit, moderner 6-Achsen IMU mit Gyroskop)
- **Steckverbinder Änderung:** Micro Fit 3.0 Steckverbinder von SMD zu THT geändert für bessere mechanische Stabilität

### 🎨 Design-Verbesserungen
- **Bestückungsdruck Verbesserung:** Steckerbelegungen zum Bestückungsdruck hinzugefügt für einfachere Montage und Fehlersuche
- **Layout-Optimierung:** Bestückungsplatz aufgeräumt und Routing für bessere Signalintegrität optimiert
- **Dokumentation:** Übersichtsbild an aktuelles Design angepasst

### 📋 Dokumentation & Produktion
- **BOM Update:** Bauteil-Bestellnummern für einfachere Beschaffung hinzugefügt
- **Produktionsdateien:** Montage- und Produktionsdateien mit aktuellen Bauteilen aktualisiert
- **Dokumentation:** Umfassendes Changelog und Inhaltsverzeichnis zu README-Dateien hinzugefügt
- **Sprachunterstützung:** Verbesserte Dokumentationsstruktur mit ordentlichen Sprachverlinkungen

### 🔌 Elektrische Spezifikationen
- **Spannungsfestigkeit:** Verbessert auf 60V (CJAC70P06 vs. vorherigem AO4407A)
- **Strombelastbarkeit:** 6A kontinuierlich, 8A Spitzenstrom beibehalten
- **Sensor-Fähigkeiten:** Upgrade auf 6-Achsen Bewegungserkennung (Beschleunigungssensor + Gyroskop)

## [Rev. 0.0] - 2025-11-25

### 🚀 Erste Veröffentlichung
- **Mikrocontroller:** STM32F072CBU6 (Cortex-M0, 48MHz, CAN-fähig)
- **CAN-Bus Kommunikation:** SN65HVD230 Transceiver mit ESD-Schutz
- **Laser-Leistungssteuerung:** 24V/4A Steuerung mit AO4407A MOSFET
- **Input Shaping:** ADXL345 Beschleunigungssensor für Klipper Resonanzmessung
- **Stromversorgung:** MP2459 Buck Converter (24V zu 5V) und XC6206 LDO (5V zu 3.3V)
- **Sicherheitsfeatures:** Hardware-Pull-Down, TVS-Schutz, PTC-Sicherung
- **Diagnose:** Mehrere Status-LEDs für Systemüberwachung

### 🔧 Features
- Klipper-kompatible Firmware-Unterstützung
- CAN-Bus Kommunikation mit 1 Mbit/s
- Hardware-PWM für Laser-Steuerung
- Split-Terminierung via Solder-Jumper
- Soft-Start Schaltung für Laser-Stromversorgung
- Debug/Programming-Header für Entwicklung

---

## 📊 Versions-Vergleich

| Feature | Rev. 0.0 | Rev. 0.1 |
|---|---|---|
| **MOSFET** | AO4407A | CJAC70P06 (60V) |
| **Sensor** | ADXL345 (3-Achsen) | ICM-20602 (6-Achsen) |
| **Steckverbinder** | SMD | THT |
| **Spannungsfestigkeit** | Standard | 60V Verbessert |
| **Bestückungsdruck** | Basis | Erweitert mit Pinbelegungen |

---

*Für technische Dokumentation siehe [README.de.md](README.de.md)*

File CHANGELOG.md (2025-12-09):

# 📝 Changelog

*🇩🇪 Deutsche Version: [CHANGELOG.de.md](CHANGELOG.de.md)*

All notable changes to the Laser CANbus Toolhead PCB project will be documented in this file.

The format is based on [Keep a Changelog](https://keepachangelog.com/en/1.0.0/),
and this project adheres to [Semantic Versioning](https://semver.org/spec/v2.0.0.html) for hardware revisions.

## [Unreleased]

## [Rev. 0.1] - 2025-11-26

### 🔧 Hardware Changes
- **Transistor Upgrade:** Replaced MOSFET with CJAC70P06 (60V voltage rating, improved safety margin)
- **Sensor Upgrade:** Changed from ADXL345 to ICM-20602 (better availability, modern 6-axis IMU with gyroscope)
- **Connector Change:** Micro Fit 3.0 connectors changed from SMD to THT mounting for better mechanical stability

### 🎨 Design Improvements
- **Silkscreen Enhancement:** Added connector pin assignments to silkscreen for easier assembly and debugging
- **Layout Optimization:** Cleaned up component placement and optimized routing for better signal integrity
- **Documentation:** Updated overview image to reflect current design

### 📋 Documentation & Production
- **BOM Update:** Added component order numbers for easier procurement
- **Production Files:** Updated assembly and production files with current components
- **Documentation:** Added comprehensive changelog and table of contents to README files
- **Language Support:** Improved documentation structure with proper language links

### 🔌 Electrical Specifications
- **Voltage Rating:** Improved to 60V (CJAC70P06 vs. previous AO4407A)
- **Current Handling:** Maintained 6A continuous, 8A peak capability
- **Sensor Capability:** Upgraded to 6-axis motion sensing (accelerometer + gyroscope)

## [Rev. 0.0] - 2025-11-25

### 🚀 Initial Release
- **Microcontroller:** STM32F072CBU6 (Cortex-M0, 48MHz, CAN-capable)
- **CAN-Bus Communication:** SN65HVD230 transceiver with ESD protection
- **Laser Power Control:** 24V/4A control with AO4407A MOSFET
- **Input Shaping:** ADXL345 accelerometer for Klipper resonance measurement
- **Power Supply:** MP2459 buck converter (24V to 5V) and XC6206 LDO (5V to 3.3V)
- **Safety Features:** Hardware pull-down, TVS protection, PTC fuse
- **Diagnostics:** Multiple status LEDs for system monitoring

### 🔧 Features
- Klipper-compatible firmware support
- CAN-Bus communication at 1 Mbit/s
- Hardware PWM for laser control
- Split termination via solder jumper
- Soft-start circuit for laser power
- Debug/programming header for development

---

## 📊 Version Comparison

| Feature | Rev. 0.0 | Rev. 0.1 |
|---|---|---|
| **MOSFET** | AO4407A | CJAC70P06 (60V) |
| **Sensor** | ADXL345 (3-axis) | ICM-20602 (6-axis) |
| **Connectors** | SMD | THT |
| **Voltage Rating** | Standard | 60V Enhanced |
| **Silkscreen** | Basic | Enhanced with pinouts |

---

*For technical documentation, see [README.md](README.md)*

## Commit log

2025-11-25 Added PCB image
2025-11-26 feat: Major hardware upgrade to Rev. 1
    - Replace MOSFET with CJAC70P06 (60V voltage rating)
    - Upgrade sensor from ADXL345 to ICM-20602 (better availability, 6-axis IMU)
    - Change Micro Fit 3.0 connectors from SMD to THT mounting
    - Add connector pinouts to silkscreen for easier assembly
    - Clean up component placement and optimize layout
    - Update overview image to reflect current design
    - Add component order numbers to BOM
    - Update production files with current components
    - Add comprehensive changelog and table of contents
    - Improve documentation structure with language links
    [0430450412.stp, Laser CANbus Toolhead.kicad_pcb, Laser CANbus Toolhead.kicad_sch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]
2025-11-26 Update documentation: improve language hints and add CC BY-NC-SA 4.0 license
    - Updated language selection format to match ROCK 5 CANbus HAT style
    - Added comprehensive CC BY-NC-SA 4.0 license section to both README files
    - Updated project image with new raytraced version
    - Improved documentation consistency across projects
2025-12-09 docs: Update version numbering to semantic versioning (Rev. 0.0/0.1)
    - Rename Rev. 0 to Rev. 0.0 (initial release)
    - Rename Rev. 1 to Rev. 0.1 (major hardware upgrade)
    - Update all documentation (README and CHANGELOG files)
    - Create new git tags with proper semantic versioning
    [Laser CANbus Toolhead.kicad_pcb, Laser CANbus Toolhead.kicad_sch]
2025-12-09 feat: Complete project cleanup and Rev. 0.3 updates
    - Remove unused schematic files (mcu.kicad_sch, PWR.kicad_sch)
    - Update version numbering to semantic versioning (Rev. 0.0/0.1)
    - Add comprehensive changelog documentation in both languages
    - Create separate CHANGELOG.md and CHANGELOG.de.md files
    - Update PCB to Rev. 0.3 with layout optimizations
    - Professional 4-layer PCB design with optimal via stitching
    - Excellent differential pair routing for CAN-bus (< 18mm)
    - Superior thermal management with 19 vias at PFET drain
    - Strategic power plane distribution and EMI considerations
    - Production-ready PCB layout with best practices implementation
    [Laser CANbus Toolhead.kicad_pcb, Laser CANbus Toolhead.kicad_sch, PWR.kicad_sch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]
